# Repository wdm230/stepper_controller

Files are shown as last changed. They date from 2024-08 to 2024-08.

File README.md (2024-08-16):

# Syringe Pump Controller Project

This project provides a complete solution for building a cost-effective syringe pump controller. It includes a C# GUI application for controlling the pump, PCB designs, circuit schematics, 3D printed components, and Arduino code for the ESP32 microcontroller.

## Table of Contents

1. [Introduction](#introduction)
2. [Project Structure](#project-structure)
3. [C# GUI Application](#c-gui-application)
4. [PCB Design](#pcb-design)
5. [Circuit and PCB Files](#circuit-and-pcb-files)
6. [3D Models](#3d-models)
7. [Arduino Code](#arduino-code)
8. [Documentation](#documentation)
9. [How to Contribute](#how-to-contribute)
10. [License](#license)

## Introduction

This project is focused on developing an affordable syringe pump controller that can be assembled with readily available components. The controller is built around an ESP32 microcontroller, with a C# application providing a user-friendly interface. The hardware includes a custom PCB and 3D-printed components to house the electronics and mechanical parts.

## Project Structure

The repository is organized as follows:

- **GUI/**: C# codebase for the graphical user interface (GUI) application.
- **PCB/**: Gerber files for manufacturing the printed circuit board (PCB).
- **circuit_board/**: KiCad project files, including the circuit schematic and PCB layout.
- **models/**: 3D models for printing the syringe pump housing and related parts.
- **syringe_pump_controller.ino**: Arduino sketch for the ESP32 microcontroller, handling motor control and communication with the GUI.
- **docs.pdf**: Comprehensive documentation covering project setup, usage, and technical details.

## C# GUI Application

The C# GUI application provides control over the syringe pump's operation. Key features include:

- Configuring syringe diameter, fluid volume, and flow rate.
- Real-time motor control, including start, stop, and jog functions.
- Monitoring of current syringe position, motor RPM, and estimated time to empty.

The application is developed in C# using .NET, and the source code is located in the `GUI` directory. It can be built using Visual Studio or the .NET CLI.

## PCB Design

The custom PCB integrates the ESP32 microcontroller with the motor driver and other essential components. The Gerber files in the `PCB` directory are ready for submission to any PCB fabrication service.

## Circuit and PCB Files

The `circuit_board` directory contains the KiCad files for the project, including the full circuit schematic and PCB layout. These files are intended for users who need to modify the circuit design or manufacture their own PCBs.

## 3D Models

The `models` directory includes STL files for 3D printing the syringe pump housing and other mechanical parts. These models are designed to fit standard syringe sizes and the custom PCB.

## Arduino Code

The `syringe_pump_controller.ino` file is the Arduino code that runs on the ESP32. This code handles:

- Motor control, including speed, direction, and position tracking.
- Communication with the C# GUI over serial.
- Homing and emergency stop functions.

The code is designed to be flexible and can be modified for different hardware configurations.

## Documentation

Detailed documentation is available in `docs.pdf`, covering all aspects of the project, from hardware assembly to software configuration. It also includes troubleshooting tips, among other things.

## How to Contribute

Contributions are welcome. If you have improvements or fixes, please fork the repository, make your changes, and submit a pull request. Whether it's code enhancements, bug fixes, or documentation updates, your contributions are appreciated.

## License

This project is licensed under the MIT License. See the `LICENSE` file for more details.

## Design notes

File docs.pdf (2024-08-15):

Template C v4.3 (beta): Created by T. Robinson 01/2021

Stepper motor driver and circuit documentation

By
TITLE PAGE
Will McKelvey
wmckelv99@gmail.com
601-701-7148

Mississippi State, Mississippi

ii

TODO:

Put in more specific controls/commands stuff

Put in more Arduino IDE stuff, CP210x drivers, how to flash esp32, et.

iii

TABLE OF CONTENTS

CHAPTER

iv

APPENDIX

v

LIST OF TABLES

vi

LIST OF FIGURES

1

INTRODUCTION

### 1.1 Overview of Project

This project was developed to support the Institute for Clean Energy Technology's

(ICET) research into electrospinning filter materials. Electrospinning is a critical process in

creating high-performance filter media, and precise control over the dispensing of fluids is

essential for ensuring the quality and consistency of these materials.

Commercial syringe pumps, which are commonly used in this process, can cost upwards

of $500, making them expensive for many research and development applications. To address

this issue, the project aims to design and build a cost-effective syringe pump using readily

available components, including a stepper motor, ESP32 microcontroller, and a TMC2209

driver.

This custom syringe pump is designed to provide the same level of precision and control

as commercial units but at a fraction of the cost. By utilizing open-source hardware and software,

this project also offers flexibility for customization and adaptation to various research needs,

making it an invaluable tool for ongoing and future projects within ICET.

### 1.2 Objectives

The primary objectives of this project are as follows:

1. Design and Develop a Cost-Effective Syringe Pump:

2

- Create a syringe pump that delivers precise control over fluid dispensing using a

stepper motor and open-source hardware, significantly reducing the cost

compared to commercial alternatives.

2. Enhance Research Capabilities:
- Support ICET’s research in electrospinning filter materials by providing a reliable

and customizable tool that meets the specific requirements of electrospinning

processes.

3. Ensure Precision and Accuracy:
- Implement control algorithms and calibration procedures to ensure that the

syringe pump operates with high precision, enabling consistent and repeatable

results in fluid dispensing.

4. Provide Flexibility and Customization:
- Design the system with modular components and open-source software, allowing

for easy customization and adaptation to various research scenarios, including the

ability to adjust flow rates, syringe sizes, and other parameters.

5. Facilitate Easy Assembly and Use:
- Develop clear assembly instructions and user-friendly software interfaces,

ensuring that the syringe pump can be easily constructed, operated, and

maintained by researchers with varying levels of technical expertise.

6. Integrate Safety Features:
- Incorporate essential safety mechanisms, such as an emergency stop function and

limit controls, to ensure the safe operation of the syringe pump in a research

environment.

3

7. Promote Future Scalability and Improvements:
- Lay the groundwork for future enhancements by designing a system that can be

scaled or modified for larger applications or additional features, such as advanced

control options or integration with other laboratory equipment.

4

SYSTEM ARCHITECTURE

### 2.1 Block Diagram

The following block diagram in fig. 2.1 provides a high-level overview of the system

architecture for the syringe pump. It illustrates the major components involved in the operation

of the pump, their interactions, and the flow of control and power within the system.

At the core of the system is the ESP32 microcontroller, which serves as the central

control unit. It interfaces with the user through a graphical user interface (GUI) that allows for

setting syringe parameters, controlling the flow rate, and starting or stopping the pump. The

ESP32 processes these inputs and communicates with the TMC2209 stepper motor driver to

control the movement of the stepper motor, which in turn drives the syringe plunger to dispense

fluid.

The user controls everything from the laptop, which is connected to the ESP32 via USB.

Communication between the ESP32 and the laptop is over serial. The ESP32 is also connected to

the TMC2209 using a serial interface. The ESP32 sends commands to the TMC22209 to control

the motor.

Additional safety and monitoring features, such as limit switches and an emergency stop

button, are integrated into the system to ensure reliable and safe operation. The power supply

provides the necessary energy to all components, ensuring consistent performance of the syringe

pump.

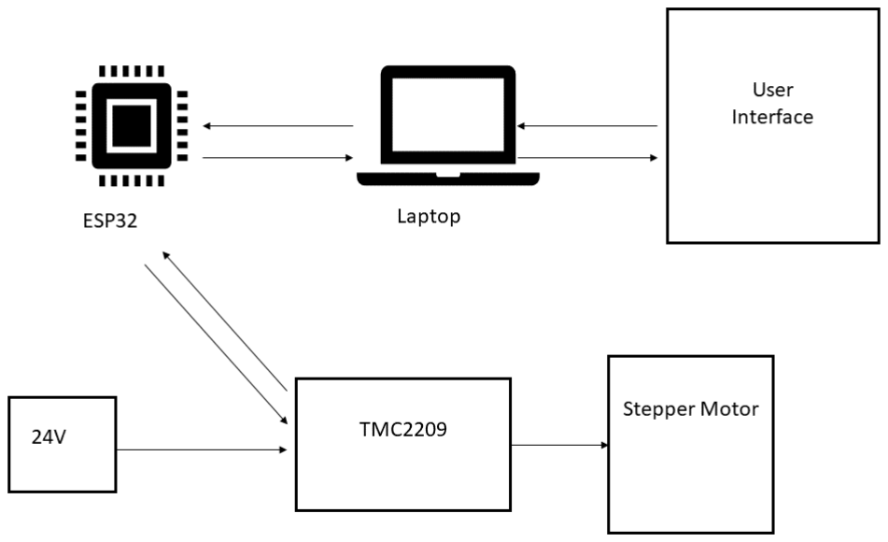
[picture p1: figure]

5

Figure 2.1 Block diagram of stepper controller

### 2.2 System Components

The syringe pump system is composed of several key components, each playing a crucial

role in its operation. Below is a detailed overview of these components and their respective

functions:

### 2.2.1 ESP32 Microcontroller

- Function: The ESP32 serves as the brain of the system, managing the control logic,

processing user inputs from the GUI, and sending control signals to the stepper motor

driver.

- Key Features:
- Dual-core processor for efficient multitasking.
- Built-in Wi-Fi and Bluetooth for wireless communication.
- Multiple GPIO pins for interfacing with sensors, drivers, and other peripherals.

6

### 2.2.2 TMC2209 Stepper Motor Driver

- Function: The TMC2209 driver controls the stepper motor by converting digital control

signals from the ESP32 into precise electrical pulses that dictate the motor’s movement.

- Key Features:
- StealthChop™ technology for quiet operation.
- StallGuard™ for sensorless homing and load detection.
- Configurable via UART interface for easy tuning and setup.

### 2.2.3 Stepper Motor

- Function: The stepper motor converts electrical pulses from the TMC2209 driver into

mechanical movement, driving the syringe plunger to dispense fluid at controlled rates.

- Key Features:
- High torque and precise step increments for accurate control.
- Compatible with various motor drivers, including the TMC2209.
- Suitable for applications requiring fine control over movement.

### 2.2.4 Syringe

- Function: The syringe holds the fluid to be dispensed. It is mechanically linked to the

stepper motor, which controls the movement of the plunger to regulate fluid flow.

- Key Features:
- Available in various sizes to accommodate different volumes.
- Made of durable materials compatible with a range of fluids.
- Easily replaceable for different applications.

7

### 2.2.5 User Interface (GUI)

- Function: The GUI provides an intuitive interface for the user to interact with the

system. It allows for the input of syringe parameters, flow rate settings, and real-time

control of the syringe pump.

- Key Features:
- User-friendly design with clear visual feedback.
- Real-time monitoring of system status and operation.
- Customizable settings to accommodate different research needs.

### 2.2.6 Serial Communication Interface

- Function: Facilitates communication between the ESP32 microcontroller and the GUI.

This interface transmits user commands to the ESP32 and relays system status and

feedback to the GUI.

- Key Features:
- Reliable and fast data transmission.
- Supports both wired and wireless communication options.
- Ensures synchronization between user commands and system operation.

### 2.2.7 Power Supply

- Function: The power supply provides the necessary electrical power to all system

components, ensuring stable and reliable operation.

- Key Features:
- Sufficient power output to support the stepper motor.
- Stable voltage and current regulation.

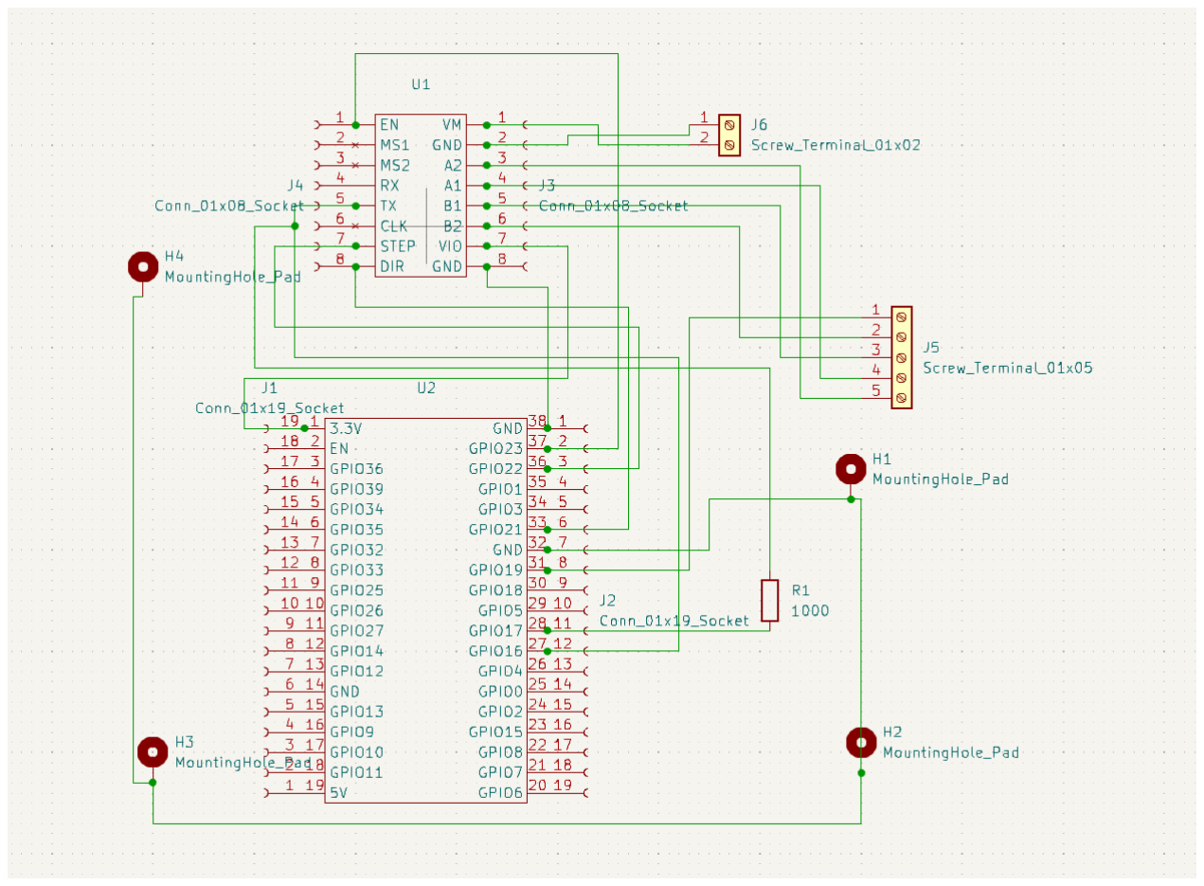
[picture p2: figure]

8

HARDWARE DESIGN

### 3.1 Circuit Schematic

Figure 3.1 below shows the circuit diagram of the stepper controller. It includes the

ESP32, the TMC2209, two screw terminals to make connections, and a 1kΩ resistor.

Figure 3.1 Circuit diagram

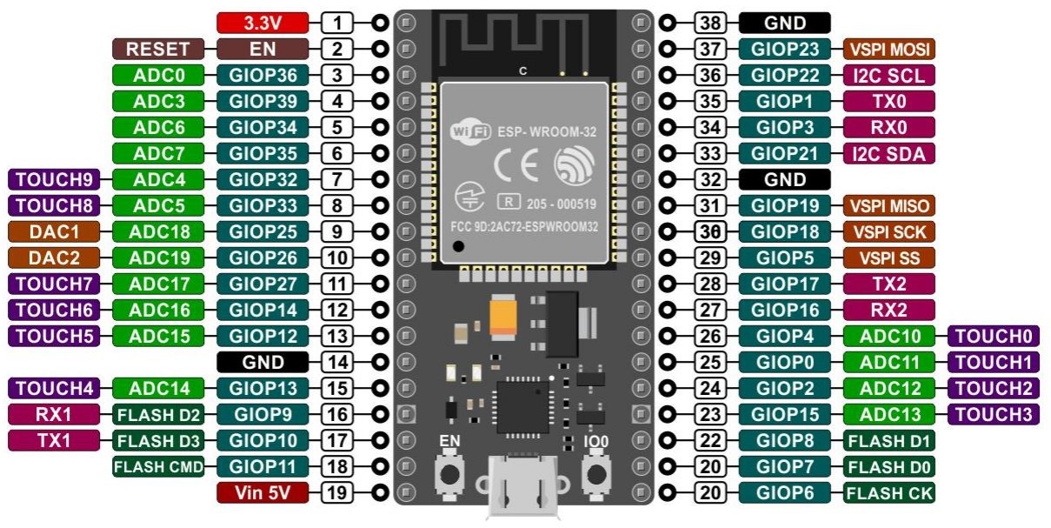
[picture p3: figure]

9

### 3.2 Component Selection

The components used in the circuit were selected due to their price and familiarity with

them. The ESP32 is a lightweight, cheap, powerful, and easy to use microcontroller that is used

in many Internet-of-Things (IoT) devices. It offers 32 GPIO connections, 3.3V and 5V outputs,

and multiple grounds. The TMC2209 was chosen again for price and familiarity. It is commonly

used in 3D printer mainboards to move the axes. It includes technology to use less power and to

keep the motor quieter than other stepper drivers. A pinout of both the ESP32 and TMC2209 are

shown below in fig. 3.x and fig. 3.x, respectively. Both components were bought from amazon,

specifically the HiLetgo ESP-WROOM-32D development board and the BIGTREETECH

TMC2209 V1.3.

Figure 3.2 ESP32 pinout

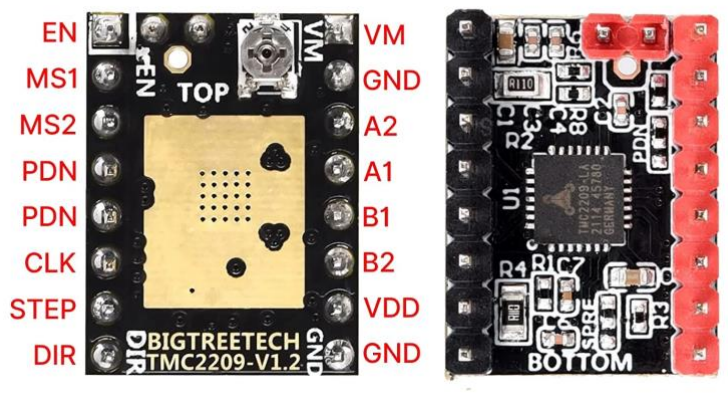
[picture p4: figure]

10

Figure 3.3 TMC2209 pinout

### 3.3 PCB Layout

Based on the circuit layout in section 3.1, the following PCB layout was created using

KiCAD. Below in fig. 3.x is the top layer of the PCB. It shows connections from the ESP32 to

the TMC2209, along with spots for the resistor and screw terminals. There are also four holes

that are meant to screw the board down. These four holes are connected to the ground pin on the

ESP32. These are used to connect the endstop to ground so it can signal the ESP32 when it is

pressed. The smaller holes in the board that are side-by-side are meant to accept 19-pin and 8-pin

headers that are to be soldered on, however the ESP32 and the TMC2209 can also both be

soldered on directly. I would recommend that headers be used so components can be easily

switched out. Fig. 3.x also shows the PCB in 3D with all the components connected.

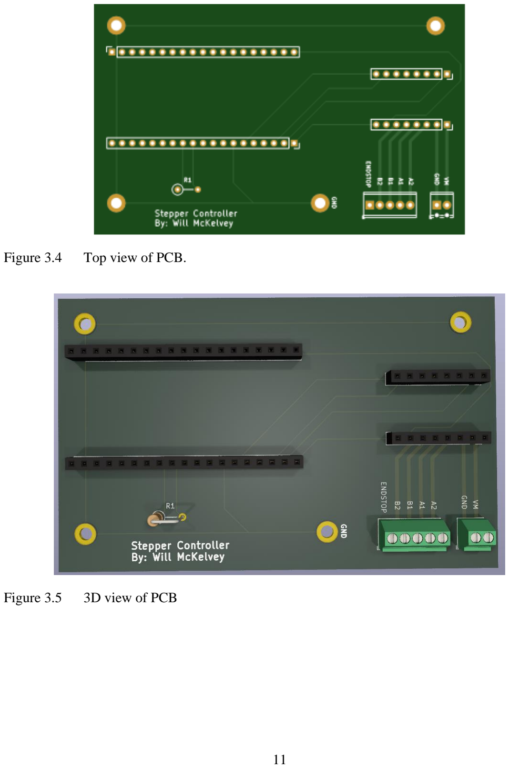
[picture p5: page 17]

11

Figure 3.4 | Top view of PCB.
Figure 3.5 | 3D view of PCB

12

SOFTWARE DESIGN

### 4.1 Firmware Overview

The firmware for the syringe pump system is designed to control the stepper motor with

precision, manage user inputs, and ensure safe and reliable operation. The firmware runs on the

ESP32 microcontroller and serves as the central control logic for the entire system. Below is an

overview of the key components and functionalities of the firmware:

### 4.1.1 System Initialization

The firmware begins by initializing all necessary peripherals and system components.

This includes configuring the GPIO pins for various inputs and outputs, such as limit switches

and status LEDs. The UART interface is set up for communication with the TMC2209 stepper

motor driver, ensuring that control signals can be transmitted accurately. Timers and interrupts

are also initialized to provide precise timing for motor control and other critical operations.

### 4.1.2 User Input Handling

The firmware continuously monitors and processes inputs from the GUI, which include

settings such as flow rate, syringe parameters, and control commands like start, stop, and

emergency stop. These inputs are validated to ensure they are within acceptable ranges and are

used to update the system's internal parameters accordingly. The firmware then provides real-

13

time feedback to the GUI, confirming received commands or alerting the user to any errors or

issues that need attention.

### 4.1.3 Stepper Motor Control

At the heart of the firmware's functionality is the control of the stepper motor, which

drives the syringe plunger. The firmware calculates the exact number of steps required to achieve

the user-defined flow rate and sends these control signals to the TMC2209 driver. The firmware

constantly monitors the motor’s position and adjusts the control signals as necessary to maintain

accurate fluid dispensing. To ensure smooth and efficient operation, acceleration and

deceleration profiles are implemented, preventing abrupt movements that could affect the

precision of the fluid flow.

### 4.1.4 Communication with TMC2209

The firmware maintains constant communication with the TMC2209 driver via the

UART interface to control the stepper motor. This communication involves sending

configuration commands, such as setting current limits or enabling stealth mode for quieter

operation. The firmware also reads status information from the TMC2209, including stall

detection and motor position, allowing it to make real-time adjustments to the motor control

parameters based on feedback from the driver.

### 4.1.5 Feedback and Status Reporting

Real-time feedback is essential for the effective operation of the syringe pump. The

firmware provides continuous status updates to the GUI, including the current position of the

syringe plunger, the operational status of the motor, and any errors or warnings that arise during

14

operation. These updates ensure that the user is fully informed of the system’s performance and

can respond quickly to any issues. Additionally, the firmware updates the status indicators, such

as LEDs, to reflect the current state of the system, providing a visual confirmation of its

operation.

### 4.2 Serial Communication Protocol

The serial communication protocol is a critical component of the syringe pump system,

enabling seamless interaction between the ESP32 microcontroller and the Graphical User

Interface (GUI). This protocol ensures that user commands are accurately transmitted to the

ESP32, and that real-time feedback is provided to the user, allowing for control and monitoring

of the syringe pump’s operation.

Serial communication between the ESP32 and TMC2209 is done using a one wire

interface. The RX pin of the TMC2209 is connected to the RX pin of the ESP32. The RX pin of

the TMC2209 is also connected to the 1kΩ resistor which is then connected to the TX pin of the

ESP32.

### 4.2.1 Communication Setup

The serial communication between the ESP32 and the GUI is established using a UART

(Universal Asynchronous Receiver-Transmitter) interface. The ESP32 is configured to

communicate over a specific baud rate, typically 115200, to ensure a balance between speed and

reliability. The communication channel is initialized during the system startup, allowing the

ESP32 to listen for incoming commands from the GUI and send status updates in return.

15

### 4.2.2 Command Structure

The protocol uses a structured format for sending and receiving commands. Each

command sent from the GUI to the ESP32 follows a predefined structure, starting with a unique

code that identifies the type of command, followed by one or more parameters depending on the

command. A special character is used to signal the end of the command, ensuring that the ESP32

correctly interprets the complete instruction. For example, a command might instruct the ESP32

to set a specific flow rate.

### 4.2.3 Command Parsing and Validation

Upon receiving a command, the ESP32 firmware parses the input to extract the command

identifier and any associated parameters. The firmware then validates the command, checking for

correct syntax and ensuring that the parameters fall within acceptable ranges. If the command is

valid, the firmware executes the corresponding action, such as adjusting the motor speed to

achieve the desired flow rate. If the command is invalid, the ESP32 sends an error message back

to the GUI, indicating the issue.

### 4.2.4 Feedback and Acknowledgment

After processing a command, the ESP32 sends an acknowledgment back to the GUI to

confirm that the command was successfully received and executed. This acknowledgment may

include the current status of the system, or any changes made as a result of the command. For

instance, the ESP32 might confirm that the flow rate has been set to the desired value. If there

was an error, the response would indicate the nature of the issue, such as an invalid flow rate.

16

### 4.2.5 Continuous Status Updates

In addition to responding to specific commands, the ESP32 periodically sends status

updates to the GUI, providing real-time information about the syringe pump’s operation. These

updates might include the current position of the syringe plunger, the operational status of the

motor, and any errors or warnings detected. These updates help the user monitor the system’s

performance and take corrective action if necessary.

### 4.3 Motor Control

Motor control is at the core of the syringe pump system, enabling precise movement of

the stepper motor to accurately dispense fluid. The firmware’s motor control logic is designed to

ensure smooth operation, with a focus on precision, reliability, and safety.

### 4.3.1 System Initialization and Configuration

During system initialization, the ESP32 configures the TMC2209 stepper motor driver,

setting parameters such as current limits, microstepping, and operation modes (e.g.,

StealthChop™ for silent operation). This initial configuration is crucial for ensuring that the

motor operates within its optimal performance range and can handle the required load without

overheating or stalling.

### 4.3.2 Step Calculation and Motion Planning

When the user sets a desired flow rate through the GUI, the firmware calculates the

corresponding number of steps the stepper motor must take to move the syringe plunger at that

rate. The calculation considers factors such as the syringe diameter and the desired volume of

17

fluid to be dispensed. The firmware then plans the motor's motion, determining the sequence of

steps needed to achieve the most accurate movement possible.

### 4.3.3 Acceleration and Deceleration Profiles

To prevent sudden starts and stops that could lead to inaccuracies or mechanical stress,

the firmware implements acceleration and deceleration profiles. These profiles gradually ramp

up the motor’s speed at the beginning of a movement and gradually slow it down at the end. This

not only improves the precision of fluid dispensing but also extends the lifespan of the motor and

mechanical components by reducing wear and tear.

### 4.3.4 Real-Time Motor Control

During operation, the firmware continuously monitors the motor’s position, adjusting the

control signals in real time to maintain the desired speed and position accuracy. This is important

in applications where precise fluid volumes must be dispensed, as any deviation in motor

position could lead to incorrect dosing. The firmware ensures that the motor follows the planned

motion profile exactly, making real-time corrections as needed based on feedback from the

motor driver.

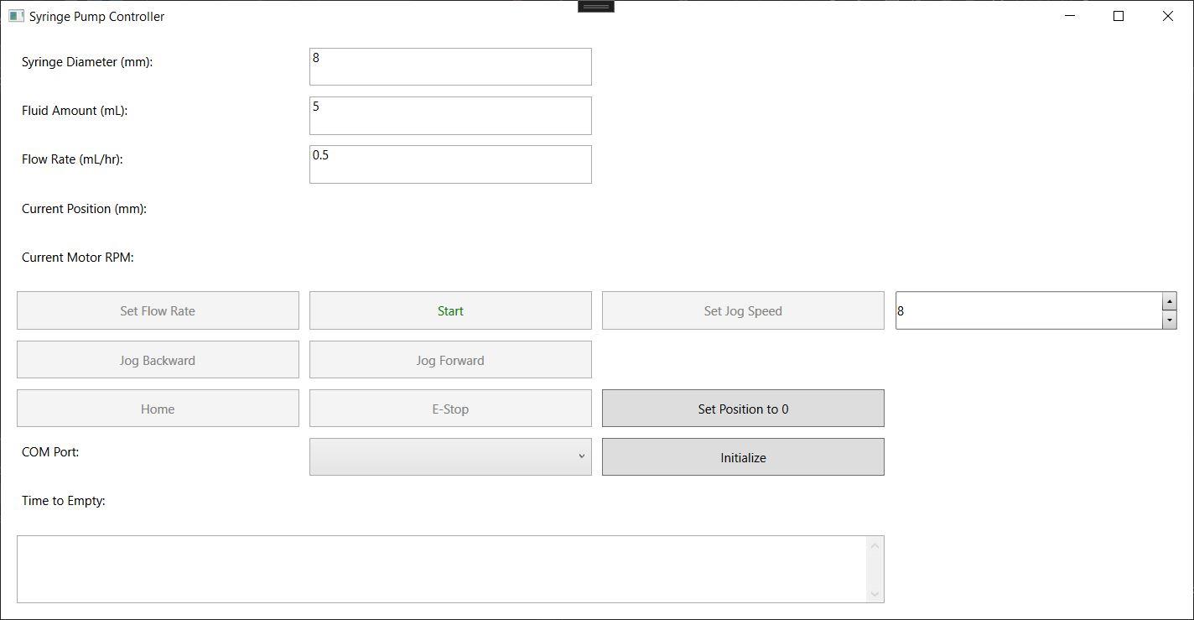
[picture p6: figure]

18

USER INTERFACE DESIGN

### 5.1 GUI Overview

The Graphical User Interface (GUI) for the syringe pump system is a critical component

that allows users to interact with and control the pump with ease and precision. Developed using

C# with Windows Presentation Foundation (WPF), the GUI offers a user-friendly interface

tailored to the needs of researchers and operators. The GUI can be seen below in fig. 5.x.

Figure 5.1 GUI

The GUI provides a clear and intuitive layout where users can input parameters such as

syringe diameter, fluid volume, and desired flow rate. It also includes controls for starting and

19

stopping the pump, as well as for adjusting settings like motor speed. Communication between

the GUI and the ESP32 microcontroller is handled through serial communication. When a user

enters a command or changes a setting within the GUI, the software packages this input into a

structured command message, which is then transmitted via the serial interface to the ESP32.

The ESP32 processes these commands in real time, adjusting the motor's operation accordingly

or performing other tasks as required.

The GUI is also responsible for receiving and displaying feedback from the ESP32. This

feedback includes real-time status updates, such as the current position of the syringe plunger,

the motor’s operational state, and any error messages or alerts. These updates are displayed

within the GUI in an accessible format, enabling users to monitor the system’s performance and

make informed decisions during operation.

To ensure reliability and user safety, the GUI includes several built-in safeguards. For

example, the interface may include warning prompts if a user attempts to set a parameter outside

of the safe operating range. Additionally, critical functions like the emergency stop are

prominently displayed and can be activated immediately from within the GUI, allowing users to

halt the pump’s operation instantly if needed.

Overall, the GUI’s combination of WPF’s graphical capabilities and C#’s backend

functionality makes it a powerful tool for controlling the syringe pump system. It bridges the gap

between the user and the underlying hardware, providing an efficient means of managing the

pump’s operation while ensuring precision, and ease of use.

20

### 5.2 Communication with Microcontroller

The communication between the GUI and the ESP32 microcontroller is the backbone of

the syringe pump system, enabling precise control and real-time feedback. This communication

is facilitated through a serial interface, where commands and status updates are exchanged in a

structured and reliable manner.

When a user interacts with the GUI—whether by setting a parameter, starting the pump,

or issuing any other command—the action triggers the creation of a command message. This

message is formatted according to a predefined protocol that ensures both the GUI and the

microcontroller can correctly interpret the instructions. Each command message typically

consists of a command identifier, which specifies the action to be taken, followed by any

necessary parameters, such as flow rate or syringe size. The command is then terminated with a

special end character, signaling the completion of the message to the microcontroller.

Consider the homing command as an example. Homing is essential for resetting the

syringe plunger to a known position, typically at the start of the syringe. When the user clicks the

"Home" button on the GUI, the software generates a homing command and sends it to the

ESP32. Upon receiving this command, the microcontroller initiates the homing routine, driving

the stepper motor in a specific direction until a limit switch is triggered, indicating that the

plunger has reached the home position. The ESP32 then stops the motor and updates the system's

internal position counter to reflect the new, known position of the syringe plunger.

After executing the command, whether it’s setting a flow rate or performing homing, the

ESP32 generates a response message to be sent back to the GUI. This response typically includes

an acknowledgment of the received command, along with any relevant status updates or error

21

messages. For example, after a successful homing operation, the response might confirm that the

homing process is complete and indicate that the system is ready for the next operation.

In addition to handling individual commands, the communication protocol also supports

continuous status updates. These updates allow the GUI to receive real-time data from the

microcontroller, such as the current position of the syringe plunger, motor status, and any alerts.

The ESP32 periodically sends these updates without requiring a specific request from the GUI,

ensuring that the user always has the latest information on the system’s performance.

The communication framework between the GUI and the microcontroller allows for

smooth operation of the syringe pump system. By ensuring that commands are transmitted and

executed accurately, and that feedback is promptly provided to the user, this communication link

is essential for maintaining the precision and reliability required for advanced fluid dispensing

tasks.

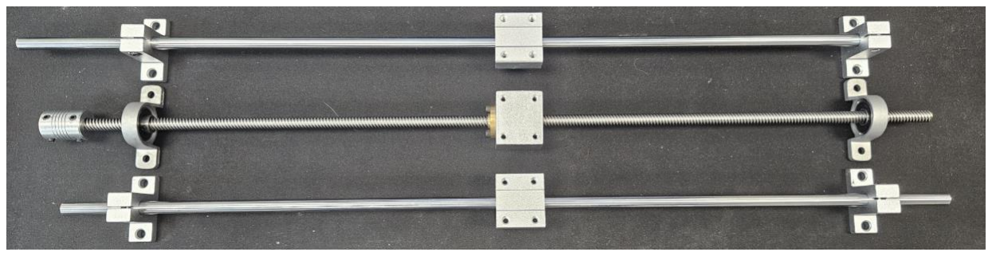
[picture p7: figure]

22

ASSEMBLY AND TESTING

### 6.1 Assembly Instructions

There are multiple components that need to be put in place before the pump is ready for

use. There are three main pieces to the syringe pump. These include the linear slide and lead

screw, the V-blocks that hold the syringe, and the motor and motor controller. All three are

mounted to aluminum extrusion to hold everything in place.

### 6.1.1 Lead Screw and Linear Slide

The linear slide and lead screw were bought off amazon, and the lead screw is a T8

thread, and can be seen in fig 6.x. This means that for every one revolution of the screw, the

threaded block moves 8mm.

Figure 6.1 Lead screw and linear slides.

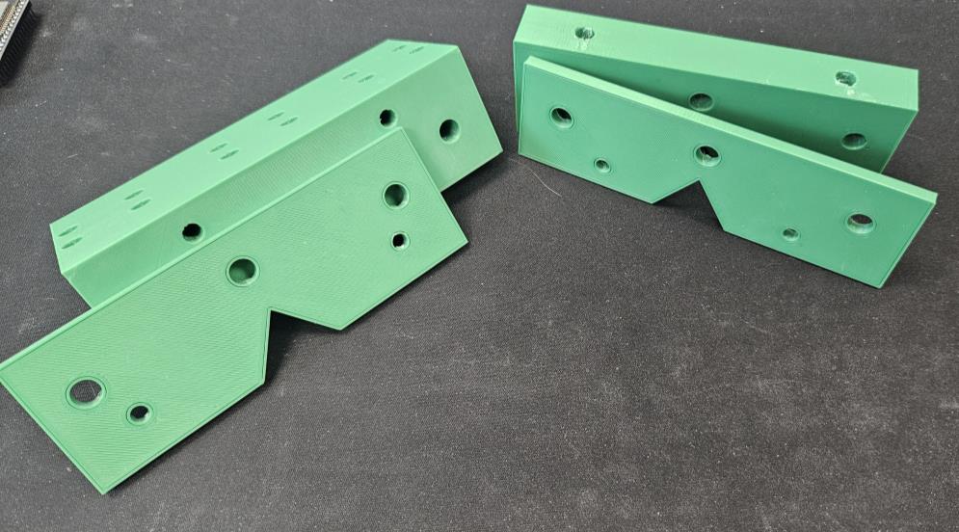
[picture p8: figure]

23

### 6.1.2 V-Block

The V-block was 3D printed and consist of four distinct parts as seen in fig. 6.x. There is

the stationary block with its holder plate, and the moving block with its holder plate. Both blocks

have holes within them to accommodate threaded inserts. These can be pressed into place with a

soldering iron to ensure a good fit. The holder plates can then be screwed into place using the

threaded insert and an M4 screw. This will hold the syringe while pumping is taking place. The

stationary block also has a place for threaded inserts on the bottom side of it so it can be held in

place while pumping. The moving block can then be screwed into the bearings and threaded

block on the linear slide.

Figure 6.2 V-Blocks

### 6.1.3 Motor and Circuit

The last main part of the syringe pump is the motor and its associated circuit. The syringe

pump motor was designed to be a NEMA 17, 1.8deg per step, stepper motor, however this can be

changed to any number of different stepper motors if it is a bidirectional motor. Steppers can

come with many different gearboxes if slower flowrates or higher step accuracy is required. The

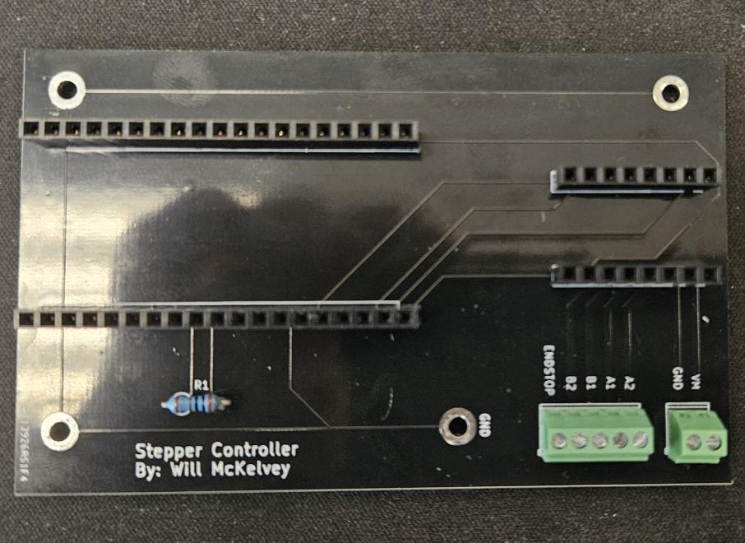
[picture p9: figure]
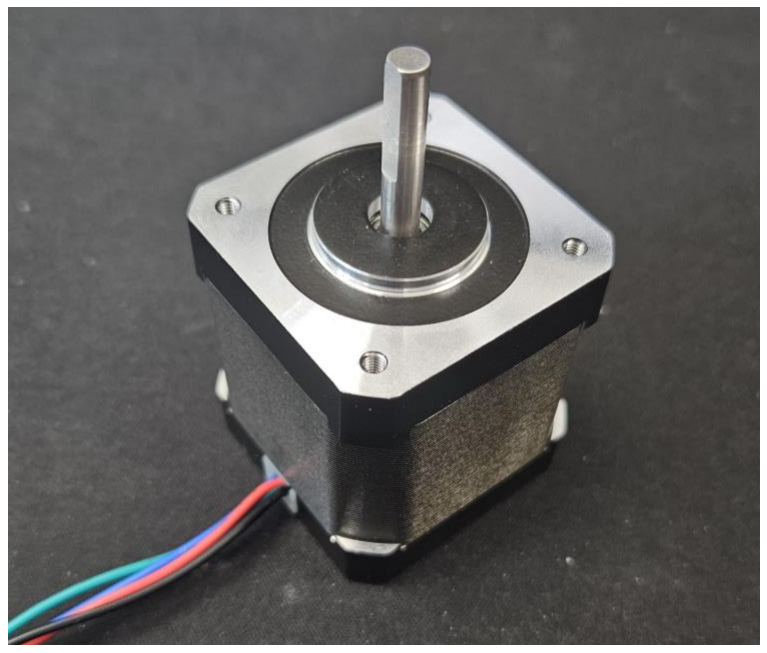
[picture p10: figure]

24

circuit and stepper can be seen below in fig 6.x and fig 6.x, respectively. The motor is connected

to the lead screw using a shaft coupling.

Figure 6.3 | Stepper circuit
Figure 6.4 | Stepper motor

25

### 6.2 Troubleshooting Guide

Some common problems that you may run into include, the motor spinning the wrong

direction, the motor vibrating and making a loud noise but not spinning, the motor being loud

and intermittently spinning, etc. This section should help alleviate some of those problems if they

should occur.

### 6.2.1 Motor Spinning the Wrong Way

After first wiring up the motor, you may encounter the motor spinning the wrong

direction. One of the main reasons for this is the wiring is wrong. Many companies use different

color wires for each coil on the stepper motor. The motor in the figure above has four different

wires, green, black, blue, and red. These each correspond to half of a coil, which is determined

by the manufacturer. In the case of the aforementioned stepper, black is A+, green is A-, red is

B+, and blue is B-. The A and B plus or minus correspond to the A1 and A2, and B1 and B2, on

the stepper controller circuit board. One must take care to check the manufacturer specifications

sheet to make sure they have everything wired correctly to the circuit board. If a pair of wires is

switched, it can cause the motor to spin the wrong direction.

Table 6.1 | Full Step 2-Phase example
Step | A+ | B+ | A- | B-
1 | + | + | - | -
2 | - | + | + | -
3 | - | - | + | +
4 | + | - | - | +
Moving down each step makes the motor turn clockwise, and moving up each step makes the motor move counter clockwise.

26

### 6.2.2 Motor Vibrating but not Spinning

Another common issue is the motor will vibrate and make loud noises but will not spin.

This can be caused by two issues; one is a wire may have come loose from the motor to the

circuit board, and the other is the speed is set too high. These can be alleviated relatively easily

by making sure all the connections are tight and secured, or by simply lowering the speed or

setting a lower max speed in firmware.

### 6.2.3 Motor vibrating and spinning intermittently

Like above in section 6.2.2, one cause for this issue is the motor speed being set too high.

The speed is right on the cusp of being low enough to not effect the motor, but the step count is

just too high for the motor. This can be resolved by setting the speed lower in the firmware.

### 6.2.4 Endstop triggering without being pressed

A common issue with configuring the endstop for homing is mistakenly setting it to

trigger when it reads LOW on the GPIO pin, when it should trigger when it reads HIGH. The

endstop switch is Normally Closed (NC), meaning that when the endstop isn’t pressed, the

circuit is complete, and the GPIO pin reads LOW. When the endstop is pressed, the circuit

opens, causing the GPIO pin to read HIGH.

To correct this issue, simply invert the logic so that homing triggers on a HIGH reading

instead of a LOW one. This adjustment ensures that the homing process is triggered correctly by

the endstop's state.

27

FUTURE IMPROVEMENTS

### 7.1 Potential Enhancements

While the current design of the syringe pump system offers precise control and reliable

operation, there are several potential enhancements that could further improve its performance,

functionality, and versatility. These enhancements could be implemented in future iterations of

the project, providing additional capabilities that cater to more advanced research and

operational needs.

### 7.1.1 Closed-Loop Stepper Motor Control

One of the most significant upgrades would be integrating a closed-loop stepper motor

control system. In the current setup, the system uses open-loop control, where the

microcontroller sends step commands to the motor without direct feedback on the motor's actual

position. By incorporating a closed-loop system with an encoder, the exact position of the

stepper motor can be continuously monitored and verified. This would allow for real-time

corrections if the motor misses steps or encounters unexpected resistance, significantly

increasing the accuracy and reliability of the fluid dispensing process.

### 7.1.2 Advanced Feedback and Monitoring Systems

Another potential enhancement could involve adding more sophisticated feedback and

monitoring systems. This might include integrating sensors to monitor the fluid pressure,

28

temperature, or even the viscosity of the fluid being dispensed. Such sensors would allow the

system to make real-time adjustments based on the properties of the fluid, improving the

consistency and quality of the output, especially in complex or sensitive applications.

### 7.1.3 Integration with IoT and Cloud Services

Another potential improvement is integrating the syringe pump system with IoT (Internet

of Things) and cloud services. This would enable remote monitoring and control of the pump

from any location, as well as the ability to log data to the cloud for long-term storage and

analysis. Such integration would be particularly useful in research settings where tracking and

analyzing large amounts of data over time is critical.

29

REFERENCES AND RESOURCES

30

GLOSSARY

31

Closed-Loop Control: A control system that continuously monitors and adjusts its

output based on feedback from the system to ensure accuracy and stability. In the context of a

stepper motor, it refers to using an encoder to track the motor's position and make real-time

corrections.

Encoder: A device that provides feedback on the position, speed, or direction of a motor

or other moving component. In a closed-loop control system, an encoder helps ensure precise

positioning by reporting the motor's actual position back to the controller.

ESP32 Microcontroller: A powerful, low-cost microcontroller with built-in Wi-Fi and

Bluetooth capabilities, used for managing control logic, processing inputs, and communicating

with other devices in the system.

Graphical User Interface (GUI): A visual interface that allows users to interact with the

system, input parameters, and control operations. In this project, the GUI is developed using C#

with Windows Presentation Foundation (WPF).

Homing: A process in which a machine or device returns to a known reference position,

often at the start of operation. In this project, homing involves moving the syringe plunger to a

predefined start position using a stepper motor and limit switch.

Internet of Things (IoT): A network of physical devices connected to the internet,

allowing them to collect and exchange data. Integration with IoT in the syringe pump system

would enable remote monitoring and control.

Limit Switch: A type of switch that detects the physical limits of movement in a

machine or device. When triggered, it signals the system to stop or reverse movement to prevent

damage or overtravel.

32

Motor Driver: An electronic component that controls the power and movement of a

motor. In this project, the TMC2209 stepper motor driver converts digital control signals from

the microcontroller into precise electrical pulses to drive the stepper motor.

Normally Closed (NC) Switch: A type of switch that completes a circuit when it is in its

default, unpressed state. Pressing the switch opens the circuit, causing it to break the connection.

Open-Loop Control: A control system where the controller sends commands to the

motor without receiving feedback on the actual position or status of the motor. Unlike closed-

loop control, it does not adjust based on the system's current state.

Serial Communication: A method of communication where data is transmitted one bit at

a time over a single communication line. In this project, serial communication is used between

the GUI and the ESP32 microcontroller.

Stepper Motor: A type of motor that moves in discrete steps, allowing for precise

control over its position. It is commonly used in applications requiring accurate positioning, such

as driving the syringe plunger in this project.

TMC2209 Stepper Motor Driver: A motor driver used to control the stepper motor in

this project. It features advanced technologies like StealthChop™ for quiet operation and

StallGuard™ for sensorless homing and load detection.

UART (Universal Asynchronous Receiver-Transmitter): A hardware communication

protocol used for asynchronous serial communication between devices. It is used in this project

for communication between the ESP32 microcontroller and the TMC2209 motor driver.

Windows Presentation Foundation (WPF): A graphical subsystem for rendering user

interfaces in Windows-based applications. WPF is used in this project to develop the GUI for the

syringe pump system.

33

LINKS

34

Circuit Pieces

- HiLetgo ESP32 (https://www.amazon.com/HiLetgo-ESP-WROOM-32-Development-Microcontroller-Integrated/dp/B0718T232Z?s=industrial)
- BIGTREETECH TMC2209 (https://www.amazon.com/BIGTREETECH-Direct-TMC2209-Stepper-Control/dp/B08WZFK9KT?s=industrial)
- 19-pin female header (https://www.amazon.com/Dahszhi-Female-Header-2-54mm-Connector/dp/B0CTKFVSL9?s=industrial)
- 8-pin female header (https://www.amazon.com/Yohii-Female-Headers-2-54mm-Single/dp/B07PLBC2GT?s=industrial)
- 5-pin screw terminal (https://www.amazon.com/dp/B07S3356SB/?coliid=I2Z6U7AK0450PN&colid=4COILYR4NJC4)
- 2-pin screw terminal (https://www.amazon.com/dp/B082QG88CT/?coliid=I2SDU3YAOA69ON&colid=4COILYR4NJC4)
- PCBWay for circuit board (https://www.pcbway.com/project/shareproject/stepper_controller_344cbd89.html)

Mechanical Pieces

- STEPPERONLINE Nema 17 Stepper Motor (https://www.amazon.com/STEPPERONLINE-Stepper-Bipolar-Connector-compatible/dp/B00PNEQKC0)
- Lead Screw and Linear Rod Kit (https://www.amazon.com/dp/B08B3VDLTK/?coliid=I21UKLRPL63WIR&colid=27SVQXMXZY4E4)
- Shaft Coupler (https://www.amazon.com/dp/B097TG69WC/?coliid=I3YWWOVPDL26T&colid=27SVQXMXZY4E4)

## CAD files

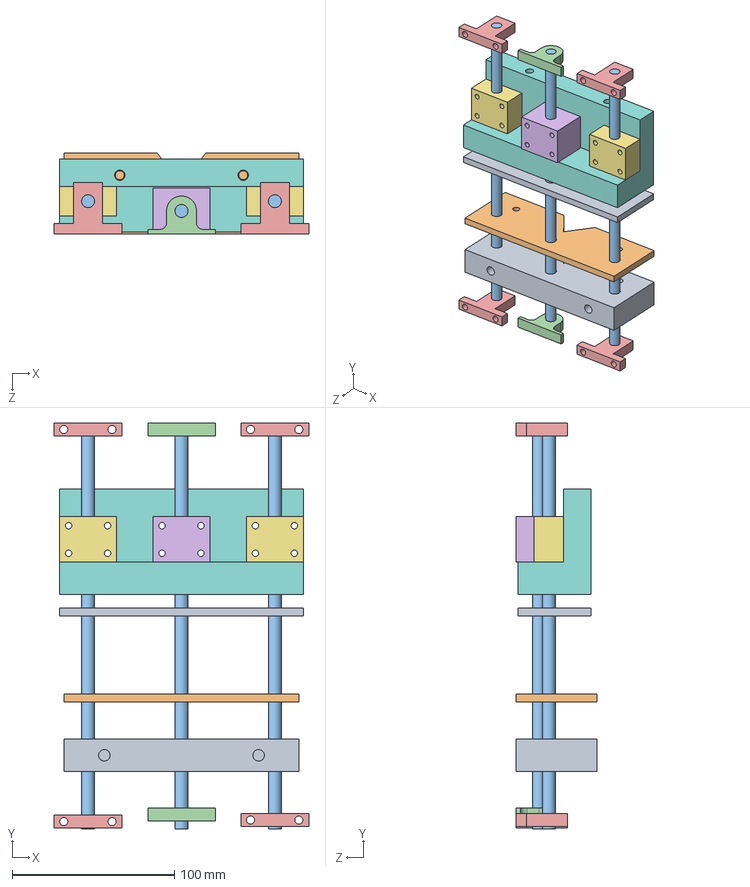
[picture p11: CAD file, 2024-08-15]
models/assembly/syringe pump assembly.SLDASM
157.0 x 250.0 x 50.0 mm
v_block
v_block_backplate
rod_screw x 3
lead_screw_holder x 2
guide_rod_holder x 4
screw_block
rod_block x 2
updated_moving_block
moving_block_backplate

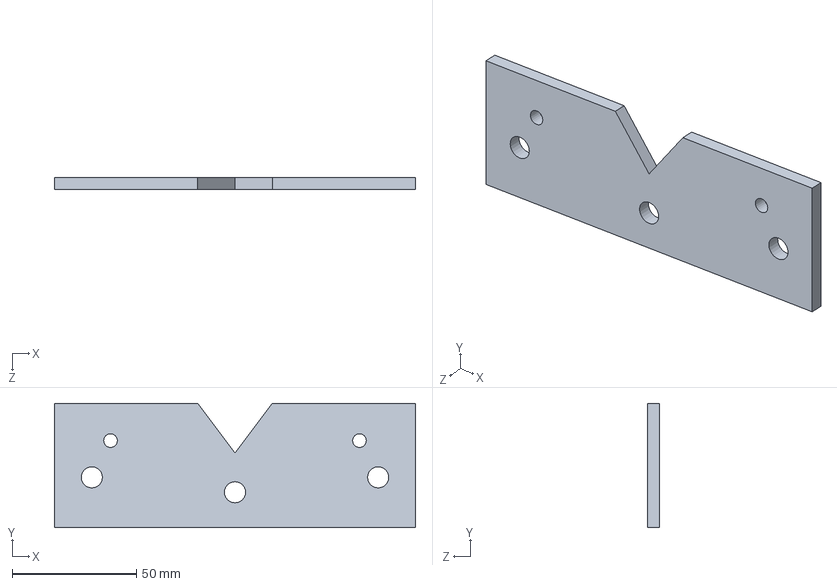
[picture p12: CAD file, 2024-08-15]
models/blocks/v_block_backplate.SLDPRT
145.0 x 50.0 x 5.00 mm

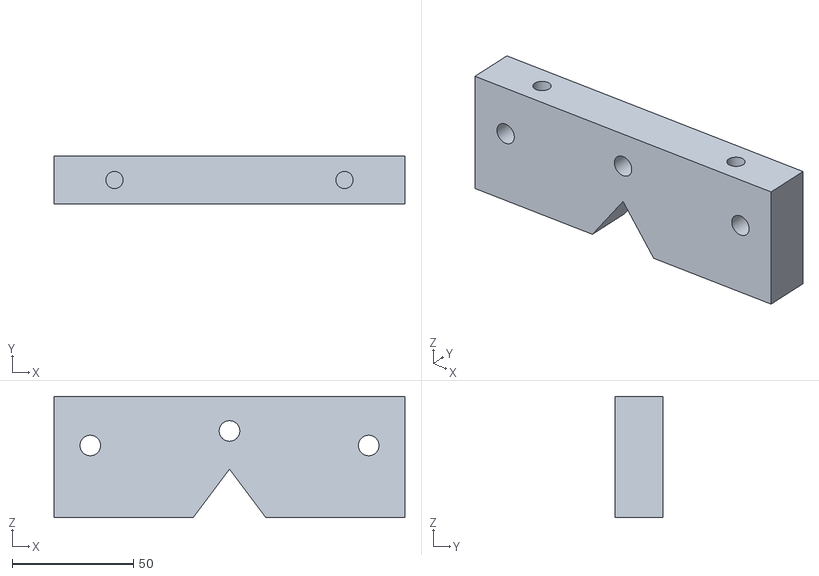
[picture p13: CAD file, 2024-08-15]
models/stl/v_block.STL
145.0 x 20.0 x 50.0

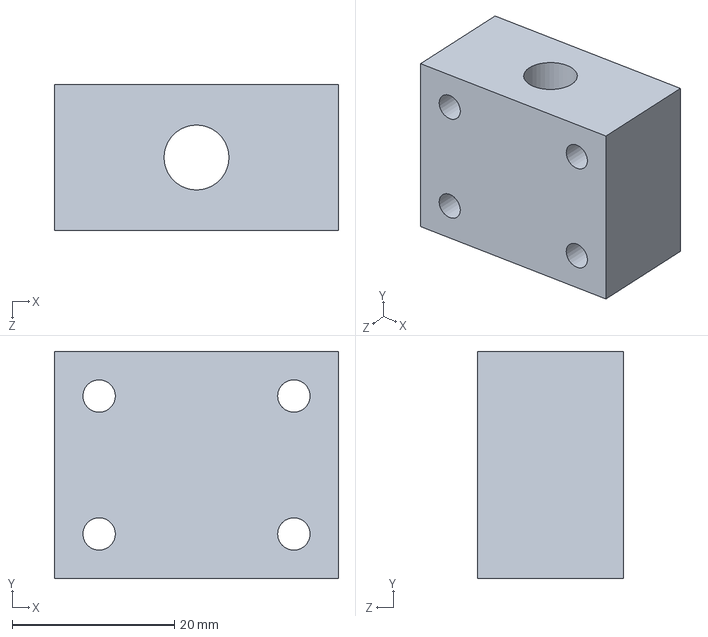
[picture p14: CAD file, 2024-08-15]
models/assembly/rod_block.SLDPRT
35.0 x 28.0 x 18.0 mm

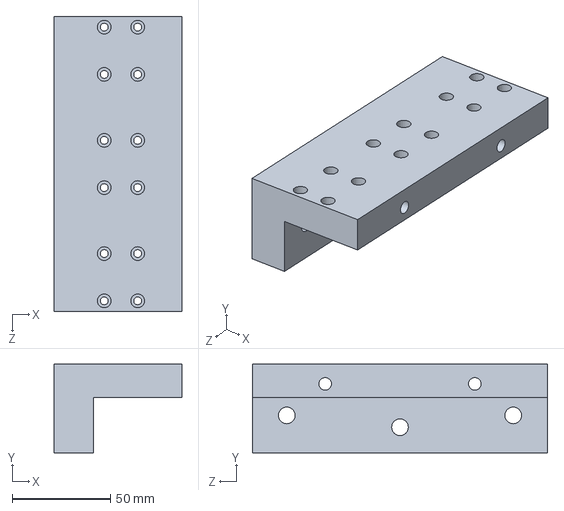
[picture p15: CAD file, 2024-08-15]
models/blocks/updated_moving_block.SLDPRT
65.0 x 45.0 x 150.0 mm

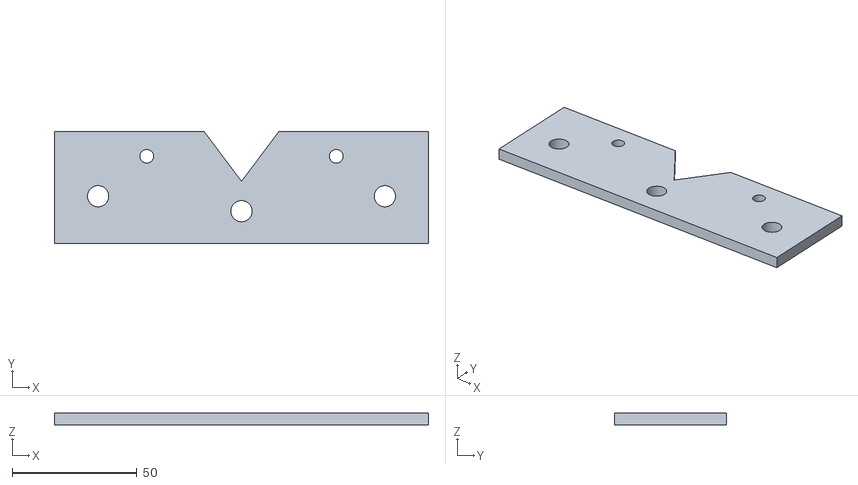
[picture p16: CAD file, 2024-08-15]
models/stl/moving_block_backplate.STL
150.0 x 45.0 x 5.00

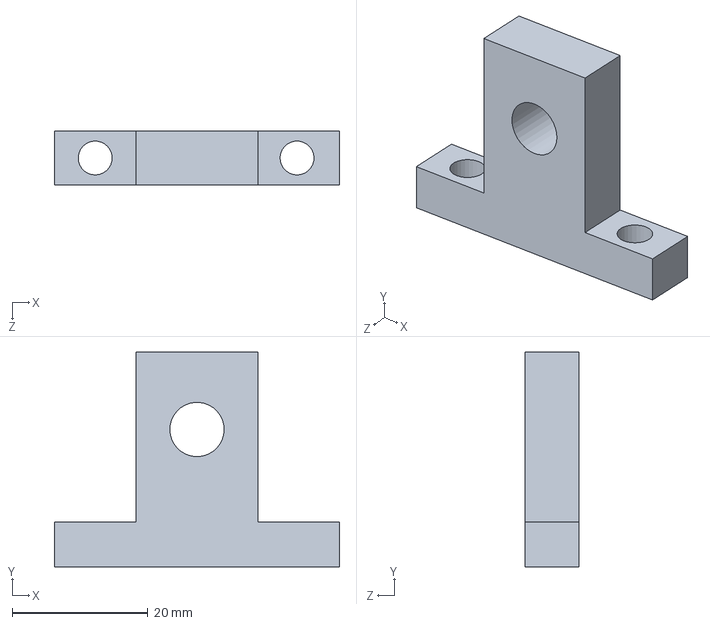
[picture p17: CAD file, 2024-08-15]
models/assembly/guide_rod_holder.SLDPRT
42.0 x 31.6 x 8.00 mm

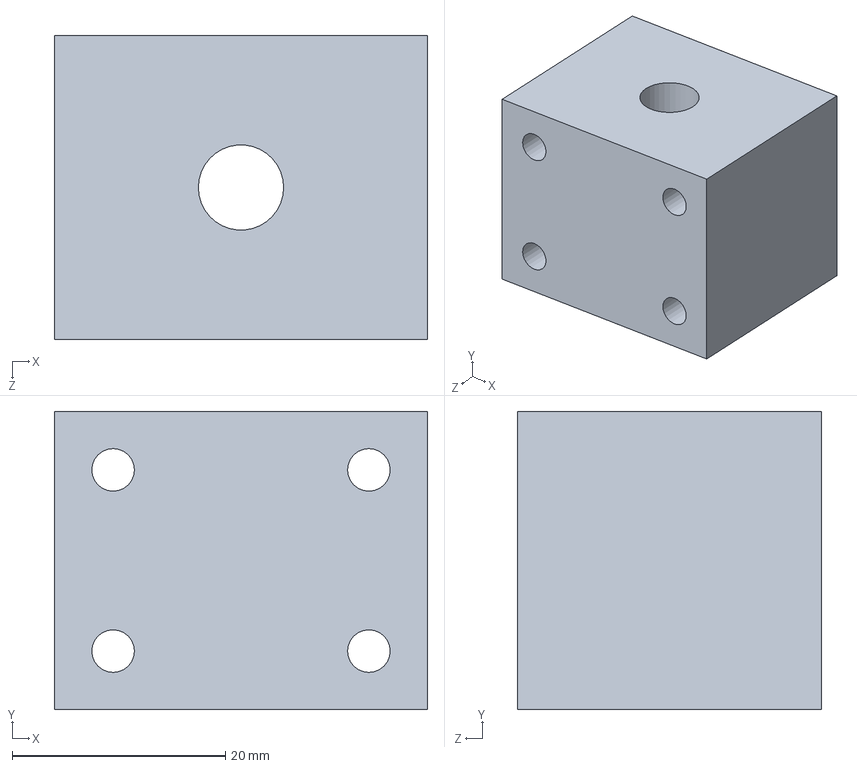
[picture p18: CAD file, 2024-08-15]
models/assembly/screw_block.SLDPRT
35.0 x 28.0 x 28.5 mm

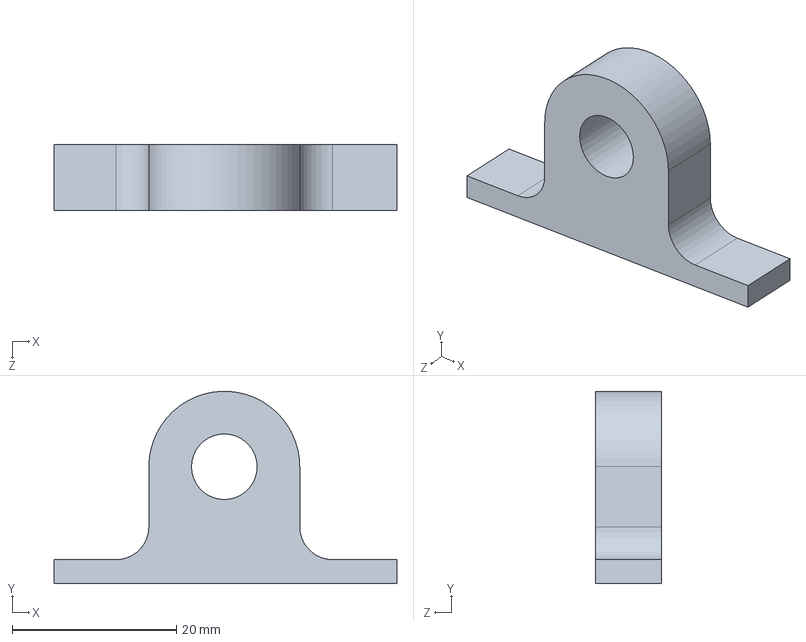
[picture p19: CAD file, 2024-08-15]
models/assembly/lead_screw_holder.SLDPRT
41.8 x 23.4 x 8.00 mm

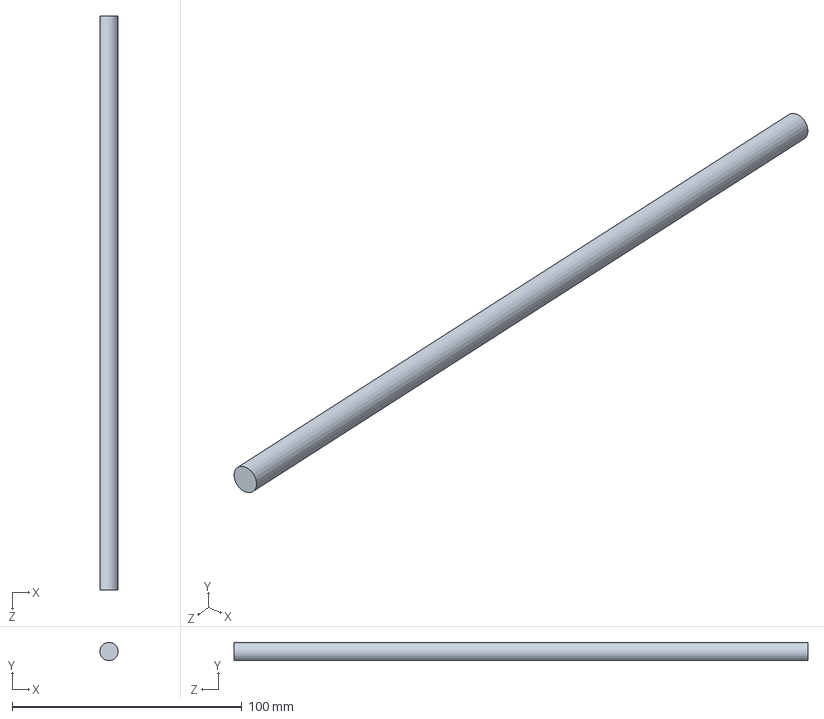
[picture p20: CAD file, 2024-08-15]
models/assembly/rod_screw.SLDPRT
8.00 x 8.00 x 250.0 mm

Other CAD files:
models/blocks/moving_block_backplate.SLDPRT
models/stl/v_block_backplate.STL
models/blocks/v_block.SLDPRT
models/stl/updated_moving_block.STL

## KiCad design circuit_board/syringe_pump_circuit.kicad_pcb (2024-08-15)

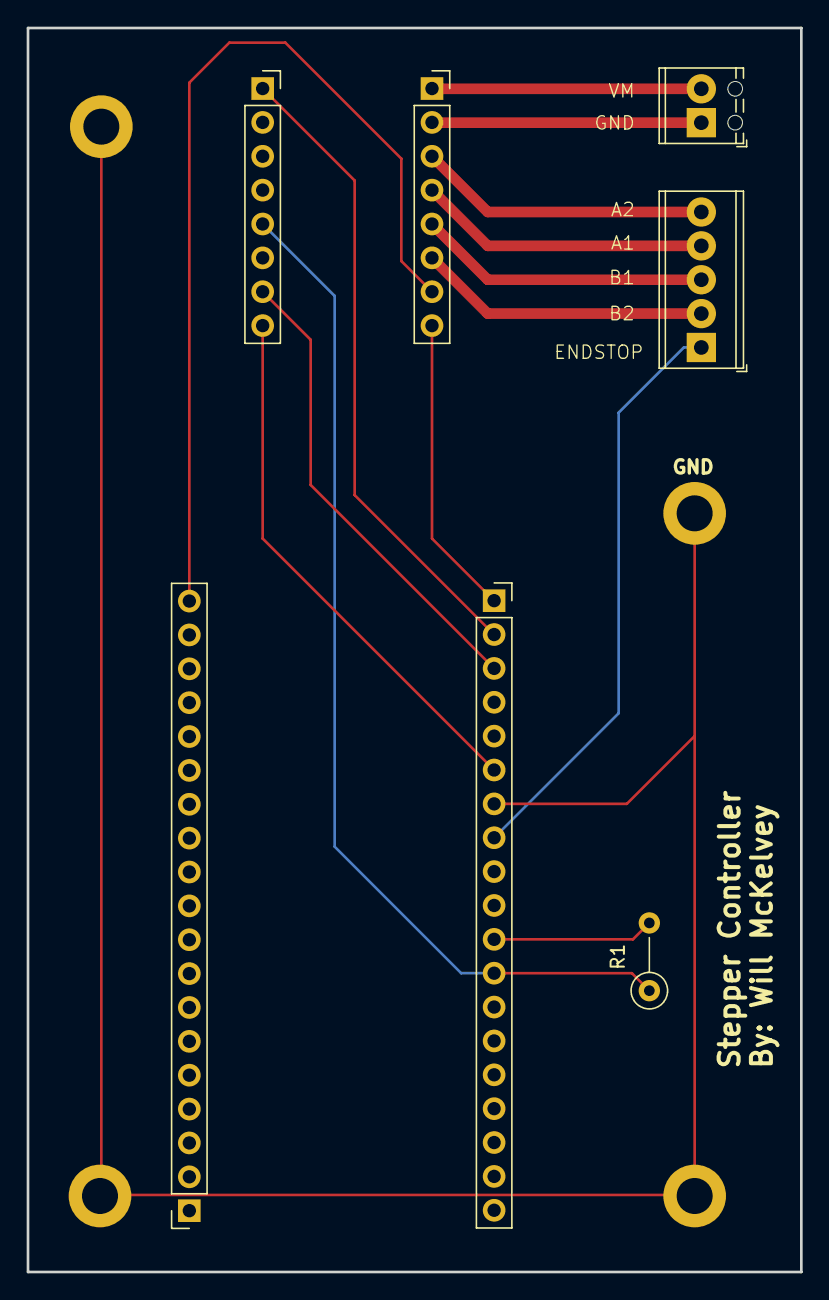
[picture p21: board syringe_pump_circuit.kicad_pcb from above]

Board: 2 copper layers, 58.0 x 93.3 mm, 11 parts (0 on the bottom side), 15 nets.

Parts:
H1, H2, H3, H4: MountingHole_Pad; MountingHole_2.7mm_M2.5_DIN965_Pad
J1, J2: Conn_01x19_Socket; PinSocket_1x19_P2.54mm_Vertical
J3, J4: Conn_01x08_Socket; PinSocket_1x08_P2.54mm_Vertical
J5: Screw_Terminal_01x05; TerminalBlock_Phoenix_MPT-0,5-5-2.54_1x05_P2.54mm_Horizontal
J6: Screw_Terminal_01x02; TerminalBlock_Phoenix_MPT-0,5-2-2.54_1x02_P2.54mm_Horizontal
R1: 1000; R_Axial_DIN0207_L6.3mm_D2.5mm_P5.08mm_Vertical

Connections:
unnamed: J1.19, J3.7
unnamed: J2.1, J3.8
unnamed: J2.2, J4.1
unnamed: J2.3, J4.7
unnamed: J2.6, J4.8
unnamed: H1.1, H2.1, H3.1, H4.1, J2.7
unnamed: J2.8, J5.1
unnamed: J2.11, R1.2
unnamed: J2.12, J4.5, R1.1
unnamed: J3.1, J6.2
unnamed: J3.2, J6.1
unnamed: J3.3, J5.5
unnamed: J3.4, J5.4
unnamed: J3.5, J5.3
unnamed: J3.6, J5.2

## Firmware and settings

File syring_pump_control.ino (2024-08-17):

#include <TMC2209.h>
#include <AccelStepper.h>

// Define TMC2209 settings
#define EN_PIN 23           // Enable
#define DIR_PIN 21          // Direction
#define STEP_PIN 22         // Step
#define HOME_SWITCH_PIN 19  // Endstop switch
#define R_SENSE 0.11f       // Sense resistor value

#define NORMAL_CURRENT 1500
#define JOGGING_CURRENT 1500

#define MAX_MICROSTEPS 256
#define FULL_STEPS_PER_REV 200  // Full steps per revolution
#define SCREW_PITCH 8.0         // Lead screw pitch (mm per revolution)
#define FULL_STEPS_PER_MM (FULL_STEPS_PER_REV * MAX_MICROSTEPS / SCREW_PITCH)


HardwareSerial SerialPort2(2);

TMC2209 stepper_driver;

// Define AccelStepper instance
AccelStepper stepper(AccelStepper::DRIVER, STEP_PIN, DIR_PIN);

bool estopActivated = false;

// Number of steps per revolution
const long stepsPerRevolution = FULL_STEPS_PER_REV * MAX_MICROSTEPS / 60;
float targetSpeed = 0;
unsigned long lastUpdate = 0;
const unsigned long updateInterval = 1000; // Update every second
float jogSpeed = 8;

void setup() {
  // Setup serial communication
  Serial.begin(115200);
  SerialPort2.begin(115200, SERIAL_8N1, 16, 17);  // TMC2209 serial communication

  // Setup TMC2209
  pinMode(EN_PIN, OUTPUT);
  pinMode(HOME_SWITCH_PIN, INPUT_PULLUP);  // Configure endstop switch pin
  digitalWrite(EN_PIN, HIGH);              // Disable the driver initially

  stepper_driver.setup(SerialPort2);
  stepper_driver.setRunCurrent(NORMAL_CURRENT);
  stepper_driver.setMicrostepsPerStep(MAX_MICROSTEPS);
  stepper_driver.enableAutomaticCurrentScaling();
  stepper_driver.enableAutomaticGradientAdaptation();
  stepper_driver.enableStealthChop();
  stepper_driver.setHardwareEnablePin(EN_PIN);
  stepper_driver.enable();
  stepper_driver.disableCoolStep();

  // Setup AccelStepper
  stepper.setMaxSpeed(50 * stepsPerRevolution);     // Set the maximum speed in steps per second
  stepper.setAcceleration(1 * stepsPerRevolution);  // Set the acceleration in steps per second^2

  // Print TMC2209 settings to verify
  //printTMC2209Settings();

  Serial.println("Setup complete.");
}

void loop() {
  if (Serial.available()) {
    String command = Serial.readStringUntil('\n');
    Serial.print("Received command: ");
    Serial.println(command);
    handleCommand(command);
  }

  stepper.runSpeed();  // Ensure the stepper motor runs according to the set speed and acceleration

  unsigned long currentMillis = millis();
  if (currentMillis - lastUpdate >= updateInterval) {
    lastUpdate = currentMillis;
    updateStatus();
  }
}

void handleCommand(String command) {
    if (command.startsWith("SET_SPEED")) {
        Serial.println("Setting speed.");
        sscanf(command.c_str() + 10, "%f", &targetSpeed);

        stepper.setMaxSpeed(targetSpeed);
        stepper.setSpeed(targetSpeed);

        Serial.print("Set target speed in steps per second: ");
        Serial.println(targetSpeed);
    } else if (command == "START") {
        Serial.println("Starting stepper.");
        stepper_driver.enable();
        stepper.setSpeed(targetSpeed);
    } else if (command == "STOP") {
        Serial.println("Stopping stepper.");
        stepper.setSpeed(0);
        stepper.stop();  // Stop the motor
        stepper_driver.disable();
    } else if (command == "JOG_FORWARD") {
        Serial.println("Jogging forward.");
        stepper_driver.enable();
        stepper.setMaxSpeed(jogSpeed * stepsPerRevolution);  // Explicitly set max speed for jogging
        stepper.setAcceleration(.5 * stepsPerRevolution);    // Explicitly set acceleration for jogging
        runMotorWithSCurve(jogSpeed * stepsPerRevolution, .5 * stepsPerRevolution, 500); // Adjust timeInterval as needed
    } else if (command == "JOG_BACKWARD") {
        Serial.println("Jogging backward.");
        stepper_driver.enable();
        stepper.setMaxSpeed(jogSpeed * stepsPerRevolution);  // Explicitly set max speed for jogging
        stepper.setAcceleration(.5 * stepsPerRevolution);    // Explicitly set acceleration for jogging
        runMotorWithSCurve(-jogSpeed * stepsPerRevolution, .5 * stepsPerRevolution, 500); // Adjust timeInterval as needed
    } else if (command == "STOP_JOG") {
        Serial.println("Stopping jog.");
        runMotorWithSCurve(0, .5 * stepsPerRevolution, 500);
        stepper.setSpeed(0);
        stepper.stop();
        setNormalCurrent();
        stepper_driver.disable();
    } else if (command == "HOME") {
        Serial.println("Homing motor.");
        homeMotor();
    } else if (command == "ESTOP") {
        Serial.println("Emergency stop.");
        stepper.setSpeed(0);
        stepper.stop();
        stepper_driver.disable();
        estopActivated = true;
    } else if (command == "ENABLE") {
        stepper_driver.enable();
    } else if (command == "DISABLE") {
        stepper_driver.disable();
    } else if (command == "SETPOS_0") {
        stepper.setCurrentPosition(0);
    } else if (command.startsWith("JOGSPEED")) {
        Serial.println("Setting Jog Speed");
        sscanf(command.c_str() + 9, "%f", &jogSpeed);
        Serial.print("Set Jog Speed: ");
        Serial.println(jogSpeed);
    }
}



void homeMotor() {
    // Step 1: Move backwards until the switch is pressed
    Serial.println("Homing: Moving backwards until switch is pressed...");
    stepper_driver.enable();

    // Explicitly set speed and acceleration for homing
    stepper.setMaxSpeed(5 * stepsPerRevolution);
    stepper.setAcceleration(1 * stepsPerRevolution);

    // Use S-curve acceleration to move backwards
    runMotorWithSCurve(-5 * stepsPerRevolution, 1 * stepsPerRevolution, 2000); // Accelerate over 2 seconds

    while (!isHomeSwitchPressed()) {
        stepper.runSpeed();
        if (estopActivated) {
            return;
        }
    }

    stepper.setSpeed(0);
    stepper.stop();  // Stop the motor
    delay(500);      // Short delay after stopping

    // Step 2: Move forward 2 revolutions
    Serial.println("Homing: Moving forward 2 revolutions...");
    stepper.setAcceleration(1 * stepsPerRevolution);
    stepper.move(2 * stepsPerRevolution);

    while (stepper.distanceToGo() != 0) {
        stepper.run();
    }

    stepper.setSpeed(0);
    stepper.stop();  // Stop the motor
    delay(500);      // Short delay after stopping

    // Step 3: Slowly move backwards until the switch is pressed again
    Serial.println("Homing: Slowly moving backwards until switch is pressed again...");

    runMotorWithSCurve(-1 * stepsPerRevolution, 0.5 * stepsPerRevolution, 1000); // Accelerate over 1 second

    while (!isHomeSwitchPressed()) {
        stepper.runSpeed();
        if (estopActivated) {
            return;
        }
    }

    stepper.setSpeed(0);
    stepper.stop();  // Stop the motor
    delay(500);      // Short delay after stopping

    stepper.setCurrentPosition(0);  // Set current position as zero
    stepper_driver.disable();
    stepper.setSpeed(0);
    Serial.println("Homing complete.");
}



void runMotorWithSCurve(float targetSpeed, float acceleration, float timeInterval) {
    float currentSpeed = stepper.speed();  // Start with the current speed
    unsigned long startTime = millis();
    unsigned long elapsedTime = 0;

    while (elapsedTime < timeInterval) {
        elapsedTime = millis() - startTime;

        // Apply S-curve logic: Adjust the acceleration curve for a smoother transition
        float progress = (float)elapsedTime / timeInterval;
        float curveFactor = 3 * pow(progress, 2) - 2 * pow(progress, 3); // S-curve formula (cubic)

        float speed = currentSpeed + (targetSpeed - currentSpeed) * curveFactor;
        stepper.setSpeed(speed);
        stepper.runSpeed();  // Run the motor at the calculated speed

        // Exit if e-stop is activated
        if (estopActivated) {
            stepper.setSpeed(0);
            stepper_driver.disable();
            return;
        }
    }

    // Set the final speed to target speed
    stepper.setSpeed(targetSpeed);
}


bool isHomeSwitchPressed() {
  return digitalRead(HOME_SWITCH_PIN) == HIGH;  // Assuming LOW means pressed
}

void setNormalCurrent() {
  stepper_driver.setRunCurrent(NORMAL_CURRENT);  // Set motor current to normal value
  Serial.println("Current set to normal");
}

void setJoggingCurrent() {
  stepper_driver.setRunCurrent(JOGGING_CURRENT);  // Set motor current to jogging value
  Serial.println("Current set to jogging");
}

void updateStatus() {
  long currentPosition = stepper.currentPosition();
  float currentRPM = (stepper.speed() / stepsPerRevolution); // Convert speed to RPM

  Serial.print("Current position in steps: ");
  Serial.println(currentPosition);
  Serial.print("Current RPM: ");
  Serial.println(currentRPM);
}

/*
void printTMC2209Settings() {
  TMC2209::Settings settings = stepper_driver.getSettings();

  Serial.println("*************************");
  Serial.println("TMC2209 Settings:");
  Serial.print("settings.irun_percent = ");
  Serial.println(settings.irun_percent);
  Serial.print("settings.irun_register_value = ");
  Serial.println(settings.irun_register_value);
  Serial.print("settings.ihold_percent = ");
  Serial.println(settings.ihold_percent);
  Serial.print("settings.ihold_register_value = ");
  Serial.println(settings.ihold_register_value);
  Serial.print("settings.iholddelay_percent = ");
  Serial.println(settings.iholddelay_percent);
  Serial.print("settings.iholddelay_register_value = ");
  Serial.println(settings.iholddelay_register_value);
  Serial.print("settings.automatic_current_scaling_enabled = ");
  Serial.println(settings.automatic_current_scaling_enabled);
  Serial.print("settings.automatic_gradient_adaptation_enabled = ");
  Serial.println(settings.automatic_gradient_adaptation_enabled);
  Serial.print("settings.pwm_offset = ");
  Serial.println(settings.pwm_offset);
  Serial.print("settings.pwm_gradient = ");
  Serial.println(settings.pwm_gradient);
  Serial.print("settings.cool_step_enabled = ");
  Serial.println(settings.cool_step_enabled);
  Serial.print("settings.analog_current_scaling_enabled = ");
  Serial.println(settings.analog_current_scaling_enabled);
  Serial.print("settings.internal_sense_resistors_enabled = ");
  Serial.println(settings.internal_sense_resistors_enabled);
  Serial.println("*************************");
  Serial.println();

  // Retrieve and print hardware status
  Serial.println("*************************");
  Serial.println("hardwareDisabled()");
  bool hardware_disabled = stepper_driver.hardwareDisabled();
  Serial.print("hardware_disabled = ");
  Serial.println(hardware_disabled);
  Serial.println("*************************");
  Serial.println();

  
  // Retrieve and print status
  Serial.println("*************************");
  Serial.println("getStatus()");
  TMC2209::Status status = stepper_driver.getStatus();
  Serial.print("status.over_temperature_warning = ");
  Serial.println(status.over_temperature_warning);
  Serial.print("status.over_temperature_shutdown = ");
  Serial.println(status.over_temperature_shutdown);
  Serial.print("status.short_to_ground_a = ");
  Serial.println(status.short_to_ground_a);
  Serial.print("status.short_to_ground_b = ");
  Serial.println(status.short_to_ground_b);
  Serial.print("status.low_side_short_a = ");
  Serial.println(status.low_side_short_a);
  Serial.print("status.low_side_short_b = ");
  Serial.println(status.low_side_short_b);
  Serial.print("status.open_load_a = ");
  Serial.println(status.open_load_a);
  Serial.print("status.open_load_b = ");
  Serial.println(status.open_load_b);
  Serial.print("status.over_temperature_120c = ");
  Serial.println(status.over_temperature_120c);
  Serial.print("status.over_temperature_143c = ");
  Serial.println(status.over_temperature_143c);
  Serial.print("status.over_temperature_150c = ");
  Serial.println(status.over_temperature_150c);
  Serial.print("status.over_temperature_157c = ");
  Serial.println(status.over_temperature_157c);
  Serial.print("status.current_scaling = ");
  Serial.println(status.current_scaling);
  Serial.print("status.stealth_chop_mode = ");
  Serial.println(status.stealth_chop_mode);
  Serial.print("status.standstill = ");
  Serial.println(status.standstill);
  Serial.println("*************************");
  Serial.println();
}
*/

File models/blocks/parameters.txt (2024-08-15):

"SyringeDiameter"= 20
"SyringeLength"= 100
"PlungerDiameter"= 5
"PlungerLength"= 110
"VSlotWidth"= 30
"VSlotDepth"= 20
"FingerFlangeDiameter"= 30
"VSlotBackPlateThickness"= 5
"GuideRodDiameter"= 8.5
"LeadScrewDiameter"= 8.5
"GuideRodSpacing"= 8
"LeadScrewSpacing"= 7.5
"ThreadedInsertDiameter"= 7.1
"ThreadedInsertDepth"= 10
"MountingHoleDiameter"= 3
"MountingHoleSpacing"= 20
"BlockHeight"= 40
"BlockWidth"= 100
"BlockDepth"= 20
"VSlotAngle"= 90

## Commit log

2024-08-15 Add project files.
    [guide_rod_holder.SLDPRT, lead_screw_holder.SLDPRT, moving_block.SLDPRT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]
2024-08-16 added icon
    [guide_rod_holder.SLDPRT, lead_screw_holder.SLDPRT, moving_block.SLDPRT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]
2024-08-17 updated button turn on/off fixed estop error
